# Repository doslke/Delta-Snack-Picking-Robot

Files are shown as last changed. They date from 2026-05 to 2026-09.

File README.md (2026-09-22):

# Delta Robot Snack Picking Prototype

An automated snack-picking and weighing system built around a three-axis Delta robot. A Python controller uses an overhead camera, a Qwen vision model, and an ArUco marker to locate products and guide the moving platform. ESP32 firmware drives the servos, vacuum pump relay, and HX711 load cell. A WeChat mini-program displays a cloud-backed cart and order flow.

The system was built and tested as a physical prototype.

## Contents

- [Features](#features)
- [Technology stack](#technology-stack)
- [Architecture](#architecture)
- [Repository structure](#repository-structure)
- [How the pipeline works](#how-the-pipeline-works)
- [Getting started](#getting-started)
- [Configuration and calibration](#configuration-and-calibration)
- [Firmware protocol](#firmware-protocol)
- [Cloud data flow](#cloud-data-flow)
- [Development notes](#development-notes)
- [License](#license)

## Features

| Area | Function |
| --- | --- |
| Product detection | Identify snack names and bounding boxes with qwen3-vl-plus |
| Visual servoing | Track ArUco marker ID 4 and adjust X/Y position with a PID controller |
| Pick and weigh | Control the pump, move items to the weighing station, and read the HX711 |
| Customer interface | Bind a cart by QR code, display weighed items, and create order records |
| Inventory management | Update product names over TCP port 8888 without restarting the controller |

## Technology stack

| Layer | Technology |
| --- | --- |
| Robot controller | Python 3.10+; OpenCV with ArUco support; NumPy; Pillow; DashScope SDK; python-dotenv |
| Vision | USB camera, OpenCV undistortion and ArUco detection, Alibaba Cloud qwen3-vl-plus for product detection |
| Control and communication | Two-axis PID in Python; newline-delimited TCP commands to the ESP32 on port 8266 |
| Firmware | ESP32 Arduino C++, FreeRTOS tasks, Wi-Fi, LEDC servo PWM, HX711 Arduino library, NVS Preferences |
| Customer application | WeChat Mini Program using TypeScript, WXML, and WXSS |
| Cloud backend | WeChat Cloud Development functions in JavaScript/Node.js with wx-server-sdk and a cloud database |
| Inventory desktop tool | Python, Tkinter, ttkbootstrap, pandas, and TCP sockets |
| Design artifacts | EasyEDA schematic/PCB JSON exports, SolidWorks part files, and XLSX bills of materials |

## Architecture

~~~text
Overhead USB camera
       |
       v
Python controller -- image --> qwen3-vl-plus
       |                         |
       |                   names + bounding boxes
       |                         |
       +<------------------------+
       |
       +-- ArUco tracking + PID --> TCP :8266 --> ESP32
       |                                      |--> 3 servo outputs
       |                                      |--> pump relay and button
       |                                      +--> HX711 load cell
       |
       +-- weighted item --> machineWeigh HTTP trigger
                                      |
                                      v
                              WeChat cloud database
                                      ^
                                      |
                        WeChat Mini Program polls cart
~~~

The camera provides image-space feedback. The firmware's **[OK]** response means a move was accepted and queued; **pos** reports the most recently commanded coordinates.

## Repository structure

~~~text
Delta-Snack-Picking-Robot/
├── README.md
├── LICENSE
├── BOM/                    Electrical and structural bills of materials
├── circuit/                EasyEDA schematic and PCB exports
├── models/                 SolidWorks part files
├── video.mp4               Demonstration media
└── src/
    ├── README.md           Detailed setup guide
    ├── .env.example         DashScope key template
    ├── controller/          Camera, vision, PID, TCP, pick, and cloud client
    ├── firmware/            ESP32 Arduino sketch
    ├── configer/            Desktop inventory-distribution tool
    └── wxapp/               Mini-program and cloud functions
~~~

The main implementation files are [main.py](src/controller/main.py), [vision.py](src/controller/vision.py), [servo.py](src/controller/servo.py), [robot.py](src/controller/robot.py), [cloud.py](src/controller/cloud.py), and [delta_robot.ino](src/firmware/delta_robot.ino). See the [setup guide](src/README.md) for module-level details.

## How the pipeline works

1. **Capture and detect.** The controller requests 1920 × 1080 camera frames. If dot25.npz is loaded, OpenCV corrects lens distortion. Press **s** to start the scan loop. A frame is sent to the configured vision model, which returns item names and normalized bounding boxes.
2. **Locate the end effector.** The controller detects an ArUco DICT_4X4_50 marker with ID 4 on the moving platform. A scan is skipped when the marker is not visible.
3. **Align.** For each detected item, the controller compares its box center with the marker center. The PID output is mapped to robot X/Y movement, clamped to a maximum step and workspace, and sent over TCP. The loop stops below a 15-pixel error by default or after 25 iterations.
4. **Pick.** The platform descends in 5 mm increments. The firmware toggles the pump and sends an event when its GPIO 27 button is pressed. The controller then lifts the platform and requests the weighing position.
5. **Weigh.** The firmware samples the HX711 before and after pump release, separated by a one-second delay, and returns the difference in grams.
6. **Report and rescan.** A positive weight is posted to the cloud function when its URL is configured. The controller scans again immediately after processing a detected batch; if no target is found, it retries after ten seconds.

One model scan supplies target positions for a batch. The next scan starts after the batch has been processed.

## Getting started

The following steps cover firmware, controller, and optional cloud configuration.

### 1. Prepare firmware and hardware

Use an ESP32-compatible Arduino environment with the HX711 library and open [delta_robot.ino](src/firmware/delta_robot.ino). Connect the three servos to GPIO **14, 12, 13**, the pump relay to **26**, the button to **27**, and HX711 DOUT/SCK to **33/32**.

The firmware stores Wi-Fi credentials in NVS. The command **setwifi SSID password** writes them; reboot to apply them. Serial and TCP both feed the command handler. Check the electrical design, motion limits, and pump polarity before powering the robot.

### 2. Prepare the Python controller

Install the Python dependencies:

~~~shell
python -m pip install opencv-contrib-python numpy pillow dashscope python-dotenv
~~~

From **src/**, copy **.env.example** to **.env** and set **DASHSCOPE_API_KEY**. The configuration module requires this variable even with **--no-robot**.

Set **ROBOT_IP** and calibration values in [config.py](src/controller/config.py). Update the camera intrinsics and inventory files for the installation.

### 3. Run

~~~shell
cd src
python -m controller.main
~~~

| Option | Purpose |
| --- | --- |
| **--camera N** | Select the camera index; default 0 |
| **--intrinsics PATH** | Select the calibration NPZ file |
| **--ip ADDRESS**, **--port N** | Override the robot TCP endpoint |
| **--no-robot** | Skip the robot connection and physical moves |
| **--save** | Save annotated detection images |

Press **s** to start the scan loop and **q** to quit. **--no-robot** skips robot communication and physical movement while retaining the vision and servo-loop code path.

### 4. Configure the optional WeChat demonstration

1. Replace **YOUR_ENV_ID** in [app.ts](src/wxapp/miniprogram/app.ts) with a cloud environment ID.
2. Deploy the four functions under [cloudfunctions](src/wxapp/cloudfunctions/) and create the **products**, **carts**, and **orders** collections. The optional **config** collection supplies the displayed logo.
3. Create product records whose **name** exactly matches expected vision names. Each product uses **unitPrice** as the price per 500 g and may include an **image**.
4. Enable the machineWeigh HTTP trigger and set **MACHINE_WEIGH_URL** in [config.py](src/controller/config.py). The default value is empty, so cloud posting is disabled until configured.
5. Set **CART_ID** to match the machine's QR code content. The mini-program validates its format and polls the cart record every three seconds.

## Configuration and calibration

| Setting | Default | Meaning |
| --- | ---: | --- |
| **ROBOT_PORT** | 8266 | ESP32 TCP command port |
| **INVENTORY_SERVER_PORT** | 8888 | TCP listener for inventory updates |
| **SERVO_KP / KI / KD** | 0.30 / 0 / 0.10 | Pixel-error PID gains |
| **SERVO_TOL_PX** | 15 | Alignment threshold |
| **SERVO_MAX_ITER** | 25 | Maximum alignment iterations |
| **SERVO_MAX_STEP_MM** | 50 | Maximum single PID move |
| **CAMERA_OFFSET_U / V** | −70 / −40 px | Camera alignment offsets |
| **DESCEND_STEP_MM** | 5 | Per-command descent increment |
| **WEIGH_X / Y / Z_MM** | 195 / 0 / 150 | Weighing position |

These values are in [config.py](src/controller/config.py). The firmware independently limits ordinary coordinates to X/Y **−100…100 mm** and Z **50…280 mm**, with the weighing position exempted. Keep host and firmware limits consistent. The HX711 factor defaults to **2280.0**; calibrate it with a known mass.

The optional [dot25.npz](src/controller/dot25.npz) stores **mtx** and **dist** camera-calibration arrays. If it cannot be read, undistortion is skipped. The controller requests a resolution; the actual image size depends on the camera and driver. Recalibrate the image-to-robot mapping and offsets after moving the camera.

## Firmware protocol

The firmware accepts UTF-8, newline-delimited text on TCP port 8266 and sends a **[HELLO]** line when connected. Its main commands are:

| Command | Response or effect |
| --- | --- |
| **x,y,z** | Request a Cartesian move; **[OK]** means queued, **[ERR]** means rejected |
| **pos** | Return last commanded coordinates and servo angles |
| **home** | Request the firmware home coordinates |
| **pump_on / pump_off / pump** | Set or query the pump relay |
| **weight** | Queue a differential load-cell reading; later return **[WEIGHT]** |
| **tare** | Zero the load cell |
| **ping** | Return **[PONG]** |
| **setwifi SSID password** | Save Wi-Fi credentials to NVS through the shared serial/TCP handler |

The firmware can also push a **[PUMP] ON (button)** message when the physical button toggles the relay. The controller uses this event during descent. A TCP client idle for roughly 30 seconds is disconnected; the Python controller sends periodic pings.

## Cloud data flow

~~~text
Python cloud.py -- one item --> machineWeigh
                                  |-- lookup products.name
                                  |-- compute weight × unitPrice / 500
                                  +-- write carts.snackList
                                             |
WeChat mini-program <-- getCartList ---------+
        |
        +-- simulated payment --> completeOrder --> orders + cart deletion
~~~

The relevant cloud functions are [machineWeigh](src/wxapp/cloudfunctions/machineWeigh/index.js), [getCartList](src/wxapp/cloudfunctions/getCartList/index.js), [validateCart](src/wxapp/cloudfunctions/validateCart/index.js), and [completeOrder](src/wxapp/cloudfunctions/completeOrder/index.js).

The Python client posts one weighed item per request. machineWeigh writes that request's snackList to the cart, so the current flow displays the latest reported item. validateCart checks the QR code's ID format and allows binding before the first item is reported. The mini-program simulates checkout and then calls completeOrder to create the order record.

## Development notes

- The inventory list guides the vision-model prompt. Add a name check after inference when strict catalog matching is required.
- machineWeigh replaces snackList on each report. Merge with the existing cart if the application needs multiple picks in one checkout.
- The payment handler uses a simulated success flow. Integrate a payment service before using it for transactions.
- Serial and TCP commands share the firmware handler, including **setwifi**. Restrict network access to the robot and add command authorization for networked deployments.
- Calibrate camera mapping, robot geometry, HX711 scaling, and motion timing for each installation.

## License

See [LICENSE](LICENSE) for the included GPL v3 license text.

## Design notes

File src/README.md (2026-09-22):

# Delta Robot Snack Picking Prototype: Source Guide

This directory contains the Python controller, ESP32 firmware, WeChat mini-program, and cloud functions for the physical prototype. See the [project overview](../README.md).

## Technology stack

| Component | Technology |
| --- | --- |
| Controller and vision | Python 3.10+, OpenCV/ArUco, NumPy, Pillow, DashScope SDK, python-dotenv |
| Robot firmware | ESP32 Arduino C++, FreeRTOS, Wi-Fi/TCP, LEDC PWM, HX711 library, NVS Preferences |
| Mini-program | TypeScript, WXML, WXSS, WeChat Mini Program APIs |
| Cloud functions | JavaScript/Node.js, wx-server-sdk, WeChat Cloud Development database |
| Inventory tool | Python, Tkinter, ttkbootstrap, pandas, TCP sockets |

## Source layout

| Path | Purpose |
| --- | --- |
| [controller/main.py](controller/main.py) | Program entry point, camera preview, scanning, and pick loop |
| [controller/vision.py](controller/vision.py) | qwen3-vl-plus calls, detection parsing, and ArUco recognition |
| [controller/servo.py](controller/servo.py) | Pixel-error PID control, stepwise descent, transfer, and weighing |
| [controller/robot.py](controller/robot.py) | TCP text-protocol client for the ESP32 |
| [controller/camera.py](controller/camera.py) | Camera capture and optional lens-distortion correction |
| [controller/cloud.py](controller/cloud.py) | Posts product names and weights to a cloud function |
| [controller/config.py](controller/config.py) | IP address, workspace, PID, positions, and other settings |
| [firmware/delta_robot.ino](firmware/delta_robot.ino) | ESP32 motion, pump, button, weighing, and network tasks |
| [wxapp](wxapp/) | Mini-program and the machineWeigh, getCartList, validateCart, and completeOrder cloud functions |
| [configer](configer/) | Desktop inventory tool that can push product names to the controller over TCP |

## Code path

1. The Python program reads camera frames and looks for ArUco marker ID 4 on the moving platform.
2. Pressing **s** calls the vision model for snack names and bounding boxes. If inventory.json is available, its names are added to the prompt.
3. The controller uses the pixel error between the marker and an item's center to calculate X/Y moves with a PID controller. It sends the moves over TCP until the error reaches a threshold or the iteration limit is exceeded.
4. The platform descends in steps. The GPIO 27 contact button toggles the pump and sends an event to Python.
5. At the weighing position, the firmware samples the HX711 twice. Python switches off the pump between the readings, and the firmware returns their difference.
6. If the weight is positive and a cloud-function URL is configured, Python posts the product name and weight. The mini-program polls the cart record every three seconds.

A firmware **[OK]** response means a move was accepted and queued, not that the platform arrived. The **pos** command reports the last commanded coordinates, not a separately measured physical position.

## Setup

Configure the firmware, controller, and cloud components in that order.

### ESP32

- Open [firmware/delta_robot.ino](firmware/delta_robot.ino) in an ESP32 Arduino environment with the HX711 library.
- Connect the three servos to GPIO 14/12/13, the pump relay to GPIO 26, the button to GPIO 27, and HX711 DOUT/SCK to GPIO 33/32.
- The firmware reads Wi-Fi credentials from NVS. The **setwifi SSID password** command saves them; reboot to apply them. Serial and TCP commands use the same handler.
- Calibrate the HX711 factor, robot geometry, weighing position, and motion limits for the installation.

### Python controller

- Use Python 3.10+ with OpenCV/ArUco, NumPy, Pillow, DashScope, and python-dotenv.
- Copy **.env.example** to **.env** and set **DASHSCOPE_API_KEY**. The configuration module reads this variable even with **--no-robot**.
- Set the robot IP, camera offsets, PID values, and positions in [controller/config.py](controller/config.py). The dot25.npz camera calibration must match the camera in use; the program skips undistortion if it cannot load the file.
- Edit [controller/inventory.json](controller/inventory.json), or push an inventory list from configer to the controller's TCP port 8888. A push updates the running list and writes the file.
- From this directory, run **python -m controller.main**. Available options include **--camera**, **--intrinsics**, **--ip**, **--port**, **--no-robot**, and **--save**. Press **s** to start automatic scanning and **q** to exit.

**--no-robot** skips the TCP connection and physical movements, but the program still attempts visual servoing after a detection.

### WeChat cloud demonstration

1. Replace **YOUR_ENV_ID** in [wxapp/miniprogram/app.ts](wxapp/miniprogram/app.ts) with the cloud environment ID.
2. Deploy the four cloud functions and create the products, carts, and orders collections. The optional config collection supplies the displayed brand image.
3. Product names in products must match the names returned by vision for pricing. machineWeigh calculates a subtotal from weight and price per 500 g.
4. Enable the machineWeigh HTTP trigger and set **MACHINE_WEIGH_URL** in [controller/config.py](controller/config.py). Its default is empty, so posting begins after configuration.
5. The mini-program scans a QR code containing a cart ID and polls the cloud record. validateCart mainly checks ID syntax; it can allow binding even before a matching carts record exists.

## Integration notes

- [machineWeigh](wxapp/cloudfunctions/machineWeigh/index.js) writes the latest reported item to snackList. Merge records there if a cart should hold multiple picks.
- The [mini-program payment handler](wxapp/miniprogram/pages/index/index.ts) simulates checkout and calls completeOrder. Connect a payment service for transactions.
- The inventory list guides the model prompt. Add a post-inference name check for strict catalog matching.
- Serial and TCP share the firmware command handler. Add authorization to the robot and the cloud weighing endpoint for networked deployments.

Recalibrate the camera, suction mechanism, load cell, and motion boundaries after mechanical changes.

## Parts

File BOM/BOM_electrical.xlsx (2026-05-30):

Name | Amount
DC Power Jack (DC-005, 5.5*2.5mm) | 1
2.54mm Single Row Straight Male/Female Pin Header | as suitable
16V 1000μF Radial Aluminum Electrolytic Capacitor | 3
ESP32 | 1
DCDC 12-5 MAX 8A | 2
L298N | 1
Pump 12V | 1

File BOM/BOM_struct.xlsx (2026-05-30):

Name | Amount
2020 Aluminum Profile 30cm | 3
2020 Aluminum Profile 20cm | 6
60-degree Extruded Corner Bracket (with 2020) | 6
90-degree Extruded Corner Bracket (with 2020) | 6
PU tube 6mm | 1
ZP2-TB20MBS-H5 SMC Bellows Vacuum Pad Unit | 1
Roller Lever Micro Switch | 1
MG 996r Servo | 3
M3 Brass Threaded Inserts | 3
M3 x 12 Fully Threaded Stud | 6
3mm Rod End Bearing | 6
M3 Nylon Insert Lock Nut | 18
M3 x 12 Socket Head Cap Screw | 6
T-Nuts Assortment Kit | 30
250mm M3 Threaded Rod | 3

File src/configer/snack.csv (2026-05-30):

sku | name | short_name | category | price | weight | length | width | height | z_pick | z_up | grab_type | place | keywords | remark
S001 | 三只松鼠碧根果 | 碧根果 | 坚果炒货 | 48.8 | 14 | 35 | 30 | 12 | 110 | 180 | suction | A1 | 坚果 | 备注
S002 | 百草味夏威夷果 | 夏威夷果 | 坚果炒货 | 55.8 | 12 | 34 | 29 | 11 | 110 | 180 | suction | A1 | 坚果 | 备注
S003 | 良品铺子巴旦木 | 巴旦木 | 坚果炒货 | 39.8 | 15 | 37 | 32 | 13 | 110 | 180 | suction | A1 | 坚果 | 备注
S004 | 恰恰腰果 | 腰果 | 坚果炒货 | 62.8 | 11 | 33 | 28 | 10 | 110 | 180 | suction | A1 | 坚果 | 备注
S005 | 三只松鼠开心果 | 开心果 | 坚果炒货 | 75.0 | 13 | 36 | 31 | 12 | 110 | 180 | suction | A1 | 坚果 | 备注
S006 | 百草味炭烧腰果 | 炭烧腰果 | 坚果炒货 | 59.9 | 11 | 33 | 28 | 10 | 110 | 180 | suction | A1 | 坚果 | 备注
S007 | 良品铺子琥珀核桃仁 | 琥珀核桃 | 坚果炒货 | 45.5 | 10 | 32 | 27 | 9 | 110 | 180 | suction | A1 | 坚果 | 备注
S008 | 恰恰纸皮核桃 | 纸皮核桃 | 坚果炒货 | 32.8 | 18 | 40 | 35 | 16 | 110 | 180 | suction | A1 | 坚果 | 备注
S009 | 三只松鼠松子 | 松子 | 坚果炒货 | 68.0 | 10 | 32 | 27 | 9 | 110 | 180 | suction | A1 | 坚果 | 备注
S010 | 百草味榛子 | 榛子 | 坚果炒货 | 52.5 | 12 | 34 | 29 | 11 | 110 | 180 | suction | A1 | 坚果 | 备注
S011 | 甘源蒜香青豆 | 蒜香青豆 | 炒货 | 12.8 | 8 | 25 | 20 | 6 | 80 | 150 | clamp | B1 | 炒货 | 备注
S012 | 恰恰原味青豆 | 原味青豆 | 炒货 | 11.5 | 8 | 25 | 20 | 6 | 80 | 150 | clamp | B1 | 炒货 | 备注
S013 | 华味亨香辣花生 | 香辣花生 | 炒货 | 15.9 | 10 | 28 | 23 | 7 | 80 | 150 | clamp | B1 | 炒货 | 备注
S014 | 老街口五香花生 | 五香花生 | 炒货 | 14.5 | 10 | 28 | 23 | 7 | 80 | 150 | clamp | B1 | 炒货 | 备注
S015 | 百草味蜂蜜花生 | 蜂蜜花生 | 炒货 | 16.2 | 10 | 28 | 23 | 7 | 80 | 150 | clamp | B1 | 炒货 | 备注
S016 | 甘源蟹黄瓜子仁 | 蟹黄瓜子仁 | 炒货 | 18.8 | 7 | 24 | 19 | 5 | 80 | 150 | clamp | B1 | 炒货 | 备注
S017 | 良品铺子牛肉味蚕豆 | 牛肉蚕豆 | 炒货 | 13.9 | 9 | 27 | 22 | 6 | 80 | 150 | clamp | B1 | 炒货 | 备注
S018 | 恰恰原味蚕豆 | 原味蚕豆 | 炒货 | 12.5 | 9 | 27 | 22 | 6 | 80 | 150 | clamp | B1 | 炒货 | 备注
S019 | 口水娃香辣蚕豆 | 香辣蚕豆 | 炒货 | 14.2 | 9 | 27 | 22 | 6 | 80 | 150 | clamp | B1 | 炒货 | 备注
S020 | 恰恰南瓜子 | 南瓜子 | 炒货 | 13.5 | 8 | 25 | 20 | 6 | 80 | 150 | clamp | B1 | 炒货 | 备注
S021 | 恰恰葵花籽 | 葵花籽 | 炒货 | 10.8 | 7 | 24 | 19 | 5 | 80 | 150 | clamp | B1 | 炒货 | 备注
S022 | 恰恰西瓜子 | 西瓜子 | 炒货 | 12.2 | 8 | 25 | 20 | 6 | 80 | 150 | clamp | B1 | 炒货 | 备注
S023 | 三只松鼠蒜香花生 | 蒜香花生 | 炒货 | 15.5 | 10 | 28 | 23 | 7 | 80 | 150 | clamp | B1 | 炒货 | 备注
S024 | 恰恰黑豆 | 黑豆 | 炒货 | 14.8 | 9 | 27 | 22 | 6 | 80 | 150 | clamp | B1 | 炒货 | 备注
S025 | 三只松鼠鹰嘴豆 | 鹰嘴豆 | 炒货 | 16.5 | 9 | 27 | 22 | 6 | 80 | 150 | clamp | B1 | 炒货 | 备注
S026 | 良品铺子芒果干 | 芒果干 | 果干 | 25.8 | 9 | 27 | 22 | 6 | 90 | 160 | clamp | C1 | 果干 | 备注
S027 | 百草味草莓干 | 草莓干 | 果干 | 23.5 | 8 | 26 | 21 | 5 | 90 | 160 | clamp | C1 | 果干 | 备注
S028 | 三只松鼠蔓越莓干 | 蔓越莓干 | 果干 | 22.6 | 7 | 25 | 20 | 5 | 90 | 160 | clamp | C1 | 果干 | 备注
S029 | 百草味蓝莓干 | 蓝莓干 | 果干 | 28.2 | 7 | 25 | 20 | 5 | 90 | 160 | clamp | C1 | 果干 | 备注
S030 | 良品铺子黄桃干 | 黄桃干 | 果干 | 21.9 | 8 | 26 | 21 | 5 | 90 | 160 | clamp | C1 | 果干 | 备注
S031 | 华味亨杏干 | 杏干 | 果干 | 20.8 | 8 | 26 | 21 | 5 | 90 | 160 | clamp | C1 | 果干 | 备注
S032 | 三只松鼠西梅干 | 西梅干 | 果干 | 29.9 | 9 | 27 | 22 | 6 | 90 | 160 | clamp | C1 | 果干 | 备注
S033 | 良品铺子话梅肉 | 话梅肉 | 果干 | 18.5 | 6 | 24 | 19 | 5 | 90 | 160 | clamp | C1 | 果干 | 备注
S034 | 华味亨情人梅 | 情人梅 | 果干 | 17.8 | 7 | 25 | 20 | 5 | 90 | 160 | clamp | C1 | 果干 | 备注
S035 | 华味亨老婆梅 | 老婆梅 | 果干 | 18.2 | 7 | 25 | 20 | 5 | 90 | 160 | clamp | C1 | 果干 | 备注
S036 | 良品铺子九制话梅 | 九制话梅 | 果干 | 19.5 | 7 | 25 | 20 | 5 | 90 | 160 | clamp | C1 | 果干 | 备注
S037 | 良品铺子菠萝干 | 菠萝干 | 果干 | 22.2 | 8 | 26 | 21 | 5 | 90 | 160 | clamp | C1 | 果干 | 备注
S038 | 华味亨柠檬片 | 柠檬片 | 果干 | 16.9 | 5 | 23 | 18 | 4 | 90 | 160 | clamp | C1 | 果干 | 备注
S039 | 良品铺子荔枝干 | 荔枝干 | 果干 | 21.8 | 8 | 26 | 21 | 5 | 90 | 160 | clamp | C1 | 果干 | 备注
S040 | 百草味桂圆干 | 桂圆干 | 果干 | 22.5 | 8 | 26 | 21 | 5 | 90 | 160 | clamp | C1 | 果干 | 备注
S041 | 华味亨乌梅 | 乌梅 | 果干 | 20.8 | 7 | 25 | 20 | 5 | 90 | 160 | clamp | C1 | 果干 | 备注
S042 | 百草味樱桃干 | 樱桃干 | 果干 | 25.5 | 8 | 26 | 21 | 5 | 90 | 160 | clamp | C1 | 果干 | 备注
S043 | 良品铺子原味猪肉脯 | 原味肉脯 | 肉干 | 32.2 | 10 | 28 | 23 | 7 | 100 | 170 | clamp | D1 | 肉干 | 备注
S044 | 三只松鼠香辣肉脯 | 香辣肉脯 | 肉干 | 33.5 | 10 | 28 | 23 | 7 | 100 | 170 | clamp | D1 | 肉干 | 备注
S045 | 百草味蜜汁肉脯 | 蜜汁肉脯 | 肉干 | 32.8 | 10 | 28 | 23 | 7 | 100 | 170 | clamp | D1 | 肉干 | 备注
S046 | 百草味黑椒肉脯 | 黑椒肉脯 | 肉干 | 34.2 | 10 | 28 | 23 | 7 | 100 | 170 | clamp | D1 | 肉干 | 备注
S047 | 华味亨五香猪肉干 | 五香肉干 | 肉干 | 31.6 | 11 | 29 | 24 | 8 | 100 | 170 | clamp | D1 | 肉干 | 备注
S048 | 百草味沙爹肉干 | 沙爹肉干 | 肉干 | 32.2 | 11 | 29 | 24 | 8 | 100 | 170 | clamp | D1 | 肉干 | 备注
S049 | 三只松鼠麻辣牛肉干 | 麻辣牛肉 | 肉干 | 39.8 | 10 | 28 | 23 | 7 | 100 | 170 | clamp | D1 | 肉干 | 备注
S050 | 良品铺子五香牛肉干 | 五香牛肉 | 肉干 | 38.5 | 10 | 28 | 23 | 7 | 100 | 170 | clamp | D1 | 肉干 | 备注
S051 | 川奈良品风干牛肉 | 风干牛肉 | 肉干 | 45.9 | 11 | 29 | 24 | 8 | 100 | 170 | clamp | D1 | 肉干 | 备注
S052 | 良品铺子牛肉粒 | 牛肉粒 | 肉干 | 38.9 | 8 | 26 | 21 | 5 | 100 | 170 | clamp | D1 | 肉干 | 备注
S053 | 三只松鼠风干猪肉 | 风干猪肉 | 肉干 | 34.8 | 10 | 28 | 23 | 7 | 100 | 170 | clamp | D1 | 肉干 | 备注
S054 | 百草味香辣鱿鱼丝 | 鱿鱼丝 | 海味 | 26.6 | 8 | 26 | 21 | 5 | 95 | 165 | clamp | E1 | 海味 | 备注
S055 | 良品铺子原味鱿鱼丝 | 原味鱿鱼丝 | 海味 | 25.8 | 8 | 26 | 21 | 5 | 95 | 165 | clamp | E1 | 海味 | 备注
S056 | 三只松鼠带籽鱿鱼仔 | 鱿鱼仔 | 海味 | 29.5 | 9 | 27 | 22 | 6 | 95 | 165 | clamp | E1 | 海味 | 备注
S057 | 劲仔香酥带鱼 | 香酥带鱼 | 海味 | 24.9 | 9 | 27 | 22 | 6 | 95 | 165 | clamp | E1 | 海味 | 备注
S058 | 良品铺子香辣小黄鱼 | 小黄鱼 | 海味 | 25.5 | 8 | 26 | 21 | 5 | 95 | 165 | clamp | E1 | 海味 | 备注
S059 | 三只松鼠鳕鱼片 | 鳕鱼片 | 海味 | 25.5 | 8 | 26 | 21 | 5 | 95 | 165 | clamp | E1 | 海味 | 备注
S060 | 百草味鱿鱼头 | 鱿鱼头 | 海味 | 26.2 | 9 | 27 | 22 | 6 | 95 | 165 | clamp | E1 | 海味 | 备注
S061 | 良品铺子鱼柳 | 鱼柳 | 海味 | 25.2 | 8 | 26 | 21 | 5 | 95 | 165 | clamp | E1 | 海味 | 备注
S062 | 三只松鼠鱿鱼足 | 鱿鱼足 | 海味 | 27.5 | 10 | 28 | 23 | 7 | 95 | 165 | clamp | E1 | 海味 | 备注
S063 | 盐津铺子香辣海带结 | 海带结 | 海味 | 15.9 | 7 | 25 | 20 | 5 | 95 | 165 | clamp | E1 | 海味 | 备注
S064 | 卫龙香辣海带丝 | 海带丝 | 海味 | 14.9 | 6 | 24 | 19 | 4 | 95 | 165 | clamp | E1 | 海味 | 备注
S065 | 盐津铺子香辣鱼豆腐 | 鱼豆腐 | 豆制品 | 18.8 | 8 | 26 | 21 | 5 | 85 | 155 | clamp | F1 | 豆制品 | 备注
S066 | 良品铺子原味鱼豆腐 | 原味鱼豆腐 | 豆制品 | 18.2 | 8 | 26 | 21 | 5 | 85 | 155 | clamp | F1 | 豆制品 | 备注
S067 | 卫龙香辣魔芋爽 | 魔芋爽 | 豆制品 | 14.9 | 6 | 24 | 19 | 4 | 85 | 155 | clamp | F1 | 豆制品 | 备注
S068 | 三只松鼠麻酱魔芋爽 | 麻酱魔芋 | 豆制品 | 15.5 | 6 | 24 | 19 | 4 | 85 | 155 | clamp | F1 | 豆制品 | 备注
S069 | 邬辣妈麻辣素牛肉 | 素牛肉 | 豆制品 | 16.2 | 7 | 25 | 20 | 5 | 85 | 155 | clamp | F1 | 豆制品 | 备注
S070 | 盐津铺子麻辣豆干 | 麻辣豆干 | 豆制品 | 15.6 | 7 | 25 | 20 | 5 | 85 | 155 | clamp | F1 | 豆制品 | 备注
S071 | 良品铺子五香豆干 | 五香豆干 | 豆制品 | 15.2 | 7 | 25 | 20 | 5 | 85 | 155 | clamp | F1 | 豆制品 | 备注
S072 | 百草味香菇豆干 | 香菇豆干 | 豆制品 | 16.5 | 7 | 25 | 20 | 5 | 85 | 155 | clamp | F1 | 豆制品 | 备注
S073 | 盐津铺子泡椒豆干 | 泡椒豆干 | 豆制品 | 15.8 | 7 | 25 | 20 | 5 | 85 | 155 | clamp | F1 | 豆制品 | 备注
S074 | 三只松鼠香辣手撕素肉 | 手撕素肉 | 豆制品 | 17.8 | 8 | 26 | 21 | 5 | 85 | 155 | clamp | F1 | 豆制品 | 备注
S075 | 邬辣妈素排 | 素排 | 豆制品 | 17.2 | 7 | 25 | 20 | 5 | 85 | 155 | clamp | F1 | 豆制品 | 备注
S076 | 盐津铺子素鸡 | 素鸡 | 豆制品 | 16.5 | 7 | 25 | 20 | 5 | 85 | 155 | clamp | F1 | 豆制品 | 备注
S077 | 邬辣妈豆卷 | 豆卷 | 豆制品 | 16.2 | 7 | 25 | 20 | 5 | 85 | 155 | clamp | F1 | 豆制品 | 备注
S078 | 卫龙大面筋辣条 | 大面筋 | 豆制品 | 13.9 | 7 | 25 | 20 | 5 | 85 | 155 | clamp | F1 | 豆制品 | 备注
S079 | 三只松鼠小辣棒辣条 | 小辣棒 | 豆制品 | 14.2 | 6 | 24 | 19 | 4 | 85 | 155 | clamp | F1 | 豆制品 | 备注
S080 | 良品铺子大刀肉辣条 | 大刀肉 | 豆制品 | 14.5 | 7 | 25 | 20 | 5 | 85 | 155 | clamp | F1 | 豆制品 | 备注
S081 | 乐事原味薯片 | 原味薯片 | 膨化 | 15.5 | 7 | 25 | 20 | 5 | 80 | 150 | clamp | G1 | 膨化 | 备注
S082 | 乐事番茄薯片 | 番茄薯片 | 膨化 | 15.8 | 7 | 25 | 20 | 5 | 80 | 150 | clamp | G1 | 膨化 | 备注
S083 | 可比克烧烤薯片 | 烧烤薯片 | 膨化 | 15.9 | 7 | 25 | 20 | 5 | 80 | 150 | clamp | G1 | 膨化 | 备注
S084 | 好丽友黄瓜薯片 | 黄瓜薯片 | 膨化 | 15.6 | 7 | 25 | 20 | 5 | 80 | 150 | clamp | G1 | 膨化 | 备注
S085 | 三只松鼠番茄山药脆片 | 番茄山药 | 膨化 | 17.8 | 7 | 25 | 20 | 5 | 80 | 150 | clamp | G1 | 膨化 | 备注
S086 | 良品铺子麻辣山药脆片 | 麻辣山药 | 膨化 | 18.2 | 7 | 25 | 20 | 5 | 80 | 150 | clamp | G1 | 膨化 | 备注
S087 | 爱尚咪咪虾条 | 咪咪虾条 | 膨化 | 14.5 | 6 | 24 | 19 | 4 | 80 | 150 | clamp | G1 | 膨化 | 备注
S088 | 爱尚蟹味粒 | 蟹味粒 | 膨化 | 14.8 | 6 | 24 | 19 | 4 | 80 | 150 | clamp | G1 | 膨化 | 备注
S089 | 旺旺原味小小酥 | 原味小小酥 | 膨化 | 15.9 | 7 | 25 | 20 | 5 | 80 | 150 | clamp | G1 | 膨化 | 备注
S090 | 三只松鼠黑胡椒小小酥 | 黑椒小小酥 | 膨化 | 16.2 | 7 | 25 | 20 | 5 | 80 | 150 | clamp | G1 | 膨化 | 备注
S091 | 恰恰原味锅巴 | 原味锅巴 | 膨化 | 16.5 | 8 | 26 | 21 | 5 | 80 | 150 | clamp | G1 | 膨化 | 备注
S092 | 良品铺子香辣锅巴 | 香辣锅巴 | 膨化 | 16.8 | 8 | 26 | 21 | 5 | 80 | 150 | clamp | G1 | 膨化 | 备注
S093 | 百草味蟹黄锅巴 | 蟹黄锅巴 | 膨化 | 17.5 | 8 | 26 | 21 | 5 | 80 | 150 | clamp | G1 | 膨化 | 备注
S094 | 良品铺子川辣锅巴 | 川辣锅巴 | 膨化 | 16.9 | 8 | 26 | 21 | 5 | 80 | 150 | clamp | G1 | 膨化 | 备注
S095 | 恰恰小米锅巴 | 小米锅巴 | 膨化 | 16.5 | 8 | 26 | 21 | 5 | 80 | 150 | clamp | G1 | 膨化 | 备注
S096 | 三只松鼠麻辣土豆丝 | 麻辣土豆丝 | 膨化 | 14.9 | 7 | 25 | 20 | 5 | 80 | 150 | clamp | G1 | 膨化 | 备注
S097 | 良品铺子香辣土豆片 | 香辣土豆片 | 膨化 | 15.2 | 7 | 25 | 20 | 5 | 80 | 150 | clamp | G1 | 膨化 | 备注
S098 | 乐事原味薯条 | 原味薯条 | 膨化 | 15.8 | 7 | 25 | 20 | 5 | 80 | 150 | clamp | G1 | 膨化 | 备注
S099 | 三只松鼠蔬菜卷 | 蔬菜卷 | 膨化 | 15.5 | 7 | 25 | 20 | 5 | 80 | 150 | clamp | G1 | 膨化 | 备注
S100 | 三惠尖角脆 | 尖角脆 | 膨化 | 16.2 | 7 | 25 | 20 | 5 | 80 | 150 | clamp | G1 | 膨化 | 备注
S101 | 旺旺玉米花 | 玉米花 | 膨化 | 14.2 | 6 | 24 | 19 | 4 | 80 | 150 | clamp | G1 | 膨化 | 备注
S102 | 三只松鼠奶油玉米泡 | 奶油玉米泡 | 膨化 | 15.2 | 7 | 25 | 20 | 5 | 80 | 150 | clamp | G1 | 膨化 | 备注
S103 | 百草味巧克力玉米泡 | 巧克力玉米泡 | 膨化 | 15.5 | 7 | 25 | 20 | 5 | 80 | 150 | clamp | G1 | 膨化 | 备注
S104 | 麦酥园香葱薄脆饼干 | 香葱薄脆 | 饼干 | 14.5 | 7 | 25 | 20 | 5 | 75 | 145 | clamp | H1 | 饼干 | 备注
S105 | 百草味香葱薄脆饼干 | 百草香葱薄脆 | 饼干 | 14.9 | 7 | 25 | 20 | 5 | 75 | 145 | clamp | H1 | 饼干 | 备注
S106 | 比比赞日式海盐小圆饼 | 海盐小圆饼 | 饼干 | 16.2 | 6 | 24 | 19 | 4 | 75 | 145 | clamp | H1 | 饼干 | 备注
S107 | 麦酥园蔬菜薄脆饼干 | 蔬菜薄脆 | 饼干 | 13.5 | 6 | 24 | 19 | 4 | 75 | 145 | clamp | H1 | 饼干 | 备注
S108 | 好丽友咸蛋黄麦芽饼 | 麦芽饼 | 饼干 | 17.6 | 7 | 25 | 20 | 5 | 75 | 145 | clamp | H1 | 饼干 | 备注
S109 | 达利园鸡蛋煎饼 | 鸡蛋煎饼 | 饼干 | 15.5 | 7 | 25 | 20 | 5 | 75 | 145 | clamp | H1 | 饼干 | 备注
S110 | 旺旺牛奶饼干 | 牛奶饼干 | 饼干 | 14.2 | 7 | 25 | 20 | 5 | 75 | 145 | clamp | H1 | 饼干 | 备注
S111 | 奥利奥巧克力饼干 | 巧克力饼干 | 饼干 | 16.8 | 7 | 25 | 20 | 5 | 75 | 145 | clamp | H1 | 饼干 | 备注
S112 | 良品铺子香葱苏打饼干 | 香葱苏打 | 饼干 | 14.9 | 7 | 25 | 20 | 5 | 75 | 145 | clamp | H1 | 饼干 | 备注
S113 | 百草味奶盐苏打饼干 | 奶盐苏打 | 饼干 | 14.5 | 7 | 25 | 20 | 5 | 75 | 145 | clamp | H1 | 饼干 | 备注
S114 | 良品铺子全麦苏打饼干 | 全麦苏打 | 饼干 | 15.2 | 7 | 25 | 20 | 5 | 75 | 145 | clamp | H1 | 饼干 | 备注
S115 | 格力高黄油曲奇饼干 | 黄油曲奇 | 饼干 | 17.5 | 7 | 25 | 20 | 5 | 75 | 145 | clamp | H1 | 饼干 | 备注
S116 | 趣多多巧克力曲奇饼干 | 巧克力曲奇 | 饼干 | 18.2 | 7 | 25 | 20 | 5 | 75 | 145 | clamp | H1 | 饼干 | 备注
S117 | 百草味抹茶曲奇饼干 | 抹茶曲奇 | 饼干 | 18.5 | 7 | 25 | 20 | 5 | 75 | 145 | clamp | H1 | 饼干 | 备注
S118 | 好丽友草莓夹心饼干 | 草莓夹心 | 饼干 | 16.8 | 7 | 25 | 20 | 5 | 75 | 145 | clamp | H1 | 饼干 | 备注
S119 | 达利园巧克力夹心饼干 | 巧克力夹心 | 饼干 | 17.2 | 7 | 25 | 20 | 5 | 75 | 145 | clamp | H1 | 饼干 | 备注
S120 | 格力高巧克力威化饼干 | 巧克力威化 | 饼干 | 16.2 | 7 | 25 | 20 | 5 | 75 | 145 | clamp | H1 | 饼干 | 备注
S121 | 百草味牛奶威化饼干 | 牛奶威化 | 饼干 | 15.8 | 7 | 25 | 20 | 5 | 75 | 145 | clamp | H1 | 饼干 | 备注
S122 | 达利园早餐饼干 | 早餐饼干 | 饼干 | 15.5 | 7 | 25 | 20 | 5 | 75 | 145 | clamp | H1 | 饼干 | 备注
S123 | 比比赞芝士味饼干 | 芝士饼干 | 饼干 | 15.8 | 7 | 25 | 20 | 5 | 75 | 145 | clamp | H1 | 饼干 | 备注
S124 | 麦酥园牛乳味饼干 | 牛乳饼干 | 饼干 | 15.2 | 7 | 25 | 20 | 5 | 75 | 145 | clamp | H1 | 饼干 | 备注
S125 | 老街口红糖小麻花 | 红糖麻花 | 糕点 | 18.2 | 8 | 26 | 21 | 5 | 90 | 160 | clamp | I1 | 糕点 | 备注
S126 | 口水娃椒盐小麻花 | 椒盐麻花 | 糕点 | 17.8 | 8 | 26 | 21 | 5 | 90 | 160 | clamp | I1 | 糕点 | 备注
S127 | 友臣蜂蜜小麻花 | 蜂蜜麻花 | 糕点 | 18.5 | 8 | 26 | 21 | 5 | 90 | 160 | clamp | I1 | 糕点 | 备注
S128 | 三只松鼠香辣小麻花 | 香辣麻花 | 糕点 | 17.2 | 8 | 26 | 21 | 5 | 90 | 160 | clamp | I1 | 糕点 | 备注
S129 | 百草味抹茶麻薯 | 抹茶麻薯 | 糕点 | 19.5 | 8 | 26 | 21 | 5 | 90 | 160 | clamp | I1 | 糕点 | 备注
S130 | 良品铺子红豆麻薯 | 红豆麻薯 | 糕点 | 19.2 | 8 | 26 | 21 | 5 | 90 | 160 | clamp | I1 | 糕点 | 备注
S131 | 三只松鼠芒果麻薯 | 芒果麻薯 | 糕点 | 19.8 | 8 | 26 | 21 | 5 | 90 | 160 | clamp | I1 | 糕点 | 备注
S132 | 旺旺香草糯米糍 | 香草糯米糍 | 糕点 | 18.9 | 7 | 25 | 20 | 5 | 90 | 160 | clamp | I1 | 糕点 | 备注
S133 | 百草味巧克力糯米糍 | 巧克力糯米糍 | 糕点 | 19.2 | 7 | 25 | 20 | 5 | 90 | 160 | clamp | I1 | 糕点 | 备注
S134 | 杏花楼桂花糕 | 桂花糕 | 糕点 | 17.8 | 7 | 25 | 20 | 5 | 90 | 160 | clamp | I1 | 糕点 | 备注
S135 | 良品铺子绿豆糕 | 绿豆糕 | 糕点 | 16.5 | 7 | 25 | 20 | 5 | 90 | 160 | clamp | I1 | 糕点 | 备注
S136 | 百草味红豆糕 | 红豆糕 | 糕点 | 16.8 | 7 | 25 | 20 | 5 | 90 | 160 | clamp | I1 | 糕点 | 备注
S137 | 徐福记凤梨酥 | 凤梨酥 | 糕点 | 19.6 | 8 | 26 | 21 | 5 | 90 | 160 | clamp | I1 | 糕点 | 备注
S138 | 达利园老婆饼 | 老婆饼 | 糕点 | 17.2 | 7 | 25 | 20 | 5 | 90 | 160 | clamp | I1 | 糕点 | 备注
S139 | 徐福记糯米老婆饼 | 糯米老婆饼 | 糕点 | 17.8 | 7 | 25 | 20 | 5 | 90 | 160 | clamp | I1 | 糕点 | 备注
S140 | 三只松鼠原味雪花酥 | 原味雪花酥 | 糕点 | 20.8 | 8 | 26 | 21 | 5 | 90 | 160 | clamp | I1 | 糕点 | 备注
S141 | 百草味抹茶雪花酥 | 抹茶雪花酥 | 糕点 | 21.2 | 8 | 26 | 21 | 5 | 90 | 160 | clamp | I1 | 糕点 | 备注
S142 | 良品铺子巧克力雪花酥 | 巧克力雪花酥 | 糕点 | 21.5 | 8 | 26 | 21 | 5 | 90 | 160 | clamp | I1 | 糕点 | 备注
S143 | 良品铺子原味蒸蛋糕 | 原味蒸蛋糕 | 糕点 | 18.2 | 8 | 26 | 21 | 5 | 90 | 160 | clamp | I1 | 糕点 | 备注
S144 | 百草味芝士蒸蛋糕 | 芝士蒸蛋糕 | 糕点 | 18.8 | 8 | 26 | 21 | 5 | 90 | 160 | clamp | I1 | 糕点 | 备注
S145 | 达利园纸杯小蛋糕 | 纸杯蛋糕 | 糕点 | 19.5 | 7 | 25 | 20 | 5 | 90 | 160 | clamp | I1 | 糕点 | 备注
S146 | 三只松鼠玛芬小蛋糕 | 玛芬蛋糕 | 糕点 | 20.2 | 7 | 25 | 20 | 5 | 90 | 160 | clamp | I1 | 糕点 | 备注
S147 | 百草味红豆铜锣烧 | 红豆铜锣烧 | 糕点 | 18.9 | 8 | 26 | 21 | 5 | 90 | 160 | clamp | I1 | 糕点 | 备注
S148 | 良品铺子抹茶铜锣烧 | 抹茶铜锣烧 | 糕点 | 19.5 | 8 | 26 | 21 | 5 | 90 | 160 | clamp | I1 | 糕点 | 备注
S149 | 三只松鼠原味蛋黄酥 | 原味蛋黄酥 | 糕点 | 22.8 | 9 | 27 | 22 | 6 | 90 | 160 | clamp | I1 | 糕点 | 备注
S150 | 百草味芋泥蛋黄酥 | 芋泥蛋黄酥 | 糕点 | 23.5 | 9 | 27 | 22 | 6 | 90 | 160 | clamp | I1 | 糕点 | 备注
S151 | 良品铺子海苔肉松小贝 | 海苔肉松小贝 | 糕点 | 24.2 | 8 | 26 | 21 | 5 | 90 | 160 | clamp | I1 | 糕点 | 备注
S152 | 三只松鼠草莓肉松小贝 | 草莓肉松小贝 | 糕点 | 24.8 | 8 | 26 | 21 | 5 | 90 | 160 | clamp | I1 | 糕点 | 备注
S153 | 达利园桃酥 | 桃酥 | 糕点 | 16.8 | 7 | 25 | 20 | 5 | 90 | 160 | clamp | I1 | 糕点 | 备注
S154 | 徐福记酥饼 | 酥饼 | 糕点 | 17.2 | 7 | 25 | 20 | 5 | 90 | 160 | clamp | I1 | 糕点 | 备注
S155 | 杏花楼龙须酥 | 龙须酥 | 糕点 | 18.9 | 7 | 25 | 20 | 5 | 90 | 160 | clamp | I1 | 糕点 | 备注
S156 | 徐福记芝麻糕 | 芝麻糕 | 糕点 | 17.5 | 7 | 25 | 20 | 5 | 90 | 160 | clamp | I1 | 糕点 | 备注
S157 | 杏花楼芝麻球 | 芝麻球 | 糕点 | 18.5 | 7 | 25 | 20 | 5 | 90 | 160 | clamp | I1 | 糕点 | 备注
S158 | 杏花楼冰皮月饼 | 冰皮月饼 | 糕点 | 22.5 | 9 | 27 | 22 | 6 | 90 | 160 | clamp | I1 | 糕点 | 备注
S159 | 五芳斋五仁月饼 | 五仁月饼 | 糕点 | 21.2 | 10 | 28 | 23 | 7 | 90 | 160 | clamp | I1 | 糕点 | 备注
S160 | 徐福记原味牛轧糖 | 原味牛轧糖 | 糖果 | 17.2 | 7 | 25 | 20 | 5 | 85 | 155 | clamp | J1 | 糖果 | 备注
S161 | 三只松鼠抹茶牛轧糖 | 抹茶牛轧糖 | 糖果 | 17.8 | 7 | 25 | 20 | 5 | 85 | 155 | clamp | J1 | 糖果 | 备注
S162 | 百草味巧克力牛轧糖 | 巧克力牛轧糖 | 糖果 | 18.2 | 7 | 25 | 20 | 5 | 85 | 155 | clamp | J1 | 糖果 | 备注
S163 | 三只松鼠蔓越莓牛轧糖 | 蔓越莓牛轧糖 | 糖果 | 18.5 | 7 | 25 | 20 | 5 | 85 | 155 | clamp | J1 | 糖果 | 备注
S164 | 徐福记花生酥 | 花生酥 | 糖果 | 16.5 | 7 | 25 | 20 | 5 | 85 | 155 | clamp | J1 | 糖果 | 备注
S165 | 徐福记芝麻酥 | 芝麻酥 | 糖果 | 16.8 | 7 | 25 | 20 | 5 | 85 | 155 | clamp | J1 | 糖果 | 备注
S166 | 徐福记核桃酥 | 核桃酥 | 糖果 | 17.2 | 7 | 25 | 20 | 5 | 85 | 155 | clamp | J1 | 糖果 | 备注
S167 | 徐福记大虾酥 | 大虾酥 | 糖果 | 15.5 | 7 | 25 | 20 | 5 | 85 | 155 | clamp | J1 | 糖果 | 备注
S168 | 徐福记高粱饴 | 高粱饴 | 糖果 | 14.2 | 7 | 25 | 20 | 5 | 85 | 155 | clamp | J1 | 糖果 | 备注
S169 | 马大姐牛皮糖 | 牛皮糖 | 糖果 | 15.5 | 7 | 25 | 20 | 5 | 85 | 155 | clamp | J1 | 糖果 | 备注
S170 | 徐福记奶片 | 奶片 | 糖果 | 15.8 | 6 | 24 | 19 | 4 | 85 | 155 | clamp | J1 | 糖果 | 备注
S171 | 大白兔原味奶糖 | 原味奶糖 | 糖果 | 14.8 | 6 | 24 | 19 | 4 | 85 | 155 | clamp | J1 | 糖果 | 备注
S172 | 阿尔卑斯巧克力奶糖 | 巧克力奶糖 | 糖果 | 15.2 | 6 | 24 | 19 | 4 | 85 | 155 | clamp | J1 | 糖果 | 备注
S173 | 阿尔卑斯牛奶棒棒糖 | 牛奶棒棒糖 | 糖果 | 14.2 | 5 | 23 | 18 | 4 | 85 | 155 | clamp | J1 | 糖果 | 备注
S174 | 徐福记水果棒棒糖 | 水果棒棒糖 | 糖果 | 13.9 | 5 | 23 | 18 | 4 | 85 | 155 | clamp | J1 | 糖果 | 备注
S175 | 雅客混合水果硬糖 | 混合水果糖 | 糖果 | 12.8 | 5 | 23 | 18 | 4 | 85 | 155 | clamp | J1 | 糖果 | 备注
S176 | 雅客柠檬水果硬糖 | 柠檬水果糖 | 糖果 | 13.2 | 5 | 23 | 18 | 4 | 85 | 155 | clamp | J1 | 糖果 | 备注
S177 | 喜之郎QQ糖 | QQ糖 | 糖果 | 13.5 | 6 | 24 | 19 | 4 | 85 | 155 | clamp | J1 | 糖果 | 备注
S178 | 喜之郎芒果软糖 | 芒果软糖 | 糖果 | 14.5 | 6 | 24 | 19 | 4 | 85 | 155 | clamp | J1 | 糖果 | 备注
S179 | 喜之郎荔枝软糖 | 荔枝软糖 | 糖果 | 14.2 | 6 | 24 | 19 | 4 | 85 | 155 | clamp | J1 | 糖果 | 备注
S180 | 悠哈混合橡皮糖 | 混合橡皮糖 | 糖果 | 14.2 | 6 | 24 | 19 | 4 | 85 | 155 | clamp | J1 | 糖果 | 备注
S181 | 绿箭无糖薄荷糖 | 无糖薄荷糖 | 糖果 | 11.5 | 5 | 23 | 18 | 4 | 85 | 155 | clamp | J1 | 糖果 | 备注
S182 | 金嗓子金银花润喉糖 | 金银花润喉糖 | 糖果 | 12.2 | 5 | 23 | 18 | 4 | 85 | 155 | clamp | J1 | 糖果 | 备注
S183 | 德芙黑巧夹心巧克力 | 黑巧夹心 | 巧克力 | 20.5 | 7 | 25 | 20 | 5 | 85 | 155 | clamp | J1 | 巧克力 | 备注
S184 | 费列罗牛奶夹心巧克力 | 牛奶夹心 | 巧克力 | 19.8 | 7 | 25 | 20 | 5 | 85 | 155 | clamp | J1 | 巧克力 | 备注
S185 | 明治松露巧克力 | 松露巧克力 | 巧克力 | 23.5 | 7 | 25 | 20 | 5 | 85 | 155 | clamp | J1 | 巧克力 | 备注
S186 | 格力高巧克力棒 | 巧克力棒 | 巧克力 | 18.2 | 6 | 24 | 19 | 4 | 85 | 155 | clamp | J1 | 巧克力 | 备注
S187 | 趣多多巧克力豆 | 巧克力豆 | 巧克力 | 17.5 | 6 | 24 | 19 | 4 | 85 | 155 | clamp | J1 | 巧克力 | 备注
S188 | 德芙巧克力块 | 巧克力块 | 巧克力 | 21.2 | 7 | 25 | 20 | 5 | 85 | 155 | clamp | J1 | 巧克力 | 备注
S189 | 德芙巧克力酱 | 巧克力酱 | 巧克力 | 20.5 | 7 | 25 | 20 | 5 | 85 | 155 | clamp | J1 | 巧克力 | 备注
S190 | 明治70%黑巧克力 | 70%黑巧克力 | 巧克力 | 23.8 | 7 | 25 | 20 | 5 | 85 | 155 | clamp | J1 | 巧克力 | 备注
S191 | 三只松鼠坚果能量棒 | 坚果能量棒 | 代餐 | 24.8 | 9 | 27 | 22 | 6 | 105 | 175 | clamp | K1 | 代餐 | 备注
S192 | 百草味谷物能量棒 | 谷物能量棒 | 代餐 | 23.5 | 9 | 27 | 22 | 6 | 105 | 175 | clamp | K1 | 代餐 | 备注
S193 | 良品铺子乳清蛋白棒 | 乳清蛋白棒 | 代餐 | 26.9 | 8 | 26 | 21 | 5 | 105 | 175 | clamp | K1 | 代餐 | 备注
S194 | 达利园原味燕麦棒 | 原味燕麦棒 | 代餐 | 20.6 | 8 | 26 | 21 | 5 | 105 | 175 | clamp | K1 | 代餐 | 备注
S195 | 三只松鼠水果燕麦棒 | 水果燕麦棒 | 代餐 | 21.2 | 8 | 26 | 21 | 5 | 105 | 175 | clamp | K1 | 代餐 | 备注
S196 | 冠生园原味压缩饼干 | 原味压缩饼干 | 代餐 | 16.8 | 10 | 28 | 23 | 7 | 105 | 175 | clamp | K1 | 代餐 | 备注
S197 | 达利园巧克力压缩饼干 | 巧克力压缩饼干 | 代餐 | 17.5 | 10 | 28 | 23 | 7 | 105 | 175 | clamp | K1 | 代餐 | 备注
S198 | 良品铺子原味全麦面包 | 原味全麦面包 | 代餐 | 18.2 | 12 | 30 | 25 | 8 | 105 | 175 | clamp | K1 | 代餐 | 备注
S199 | 百草味杂粮全麦面包 | 杂粮全麦面包 | 代餐 | 18.8 | 12 | 30 | 25 | 8 | 105 | 175 | clamp | K1 | 代餐 | 备注
S200 | 达利园奶香吐司面包 | 奶香吐司 | 代餐 | 17.9 | 11 | 29 | 24 | 7 | 105 | 175 | clamp | K1 | 代餐 | 备注
S201 | 三只松鼠抹茶吐司面包 | 抹茶吐司 | 代餐 | 18.5 | 11 | 29 | 24 | 7 | 105 | 175 | clamp | K1 | 代餐 | 备注
S202 | 良品铺子全麦吐司 | 全麦吐司 | 代餐 | 18.5 | 11 | 29 | 24 | 7 | 105 | 175 | clamp | K1 | 代餐 | 备注
S203 | 百草味杂粮吐司 | 杂粮吐司 | 代餐 | 19.2 | 11 | 29 | 24 | 7 | 105 | 175 | clamp | K1 | 代餐 | 备注
S204 | 良品铺子全麦饼干 | 全麦饼干 | 代餐 | 17.5 | 8 | 26 | 21 | 5 | 105 | 175 | clamp | K1 | 代餐 | 备注
S205 | 百草味杂粮饼 | 杂粮饼 | 代餐 | 18.2 | 8 | 26 | 21 | 5 | 105 | 175 | clamp | K1 | 代餐 | 备注
S206 | 桂格燕麦片 | 燕麦片 | 代餐 | 19.8 | 10 | 28 | 23 | 7 | 105 | 175 | clamp | K1 | 代餐 | 备注
S207 | 雀巢玉米片 | 玉米片 | 代餐 | 18.5 | 9 | 27 | 22 | 6 | 105 | 175 | clamp | K1 | 代餐 | 备注
S208 | 百草味代餐奶昔 | 代餐奶昔 | 代餐 | 25.5 | 9 | 27 | 22 | 6 | 105 | 175 | clamp | K1 | 代餐 | 备注
S209 | 良品铺子蛋白代餐饼 | 蛋白代餐饼 | 代餐 | 22.8 | 8 | 26 | 21 | 5 | 105 | 175 | clamp | K1 | 代餐 | 备注
S210 | 百草味原味开心果 | 原味开心果 | 坚果炒货 | 72.8 | 13 | 36 | 31 | 12 | 110 | 180 | suction | A1 | 坚果 | 备注
S211 | 百草味盐焗巴旦木 | 盐焗巴旦木 | 坚果炒货 | 41.5 | 15 | 37 | 32 | 13 | 110 | 180 | suction | A1 | 坚果 | 备注
S212 | 良品铺子原味碧根果 | 原味碧根果 | 坚果炒货 | 46.5 | 18 | 40 | 35 | 16 | 110 | 180 | suction | A1 | 坚果 | 备注
S213 | 百草味原味夏威夷果 | 原味夏威夷果 | 坚果炒货 | 53.8 | 70 | 95 | 95 | 20 | 20 | 38 | suction | A1 | 坚果 | 备注
S214 | 良品铺子杏仁巴旦木 | 杏仁巴旦木 | 坚果炒货 | 37.5 | 52 | 80 | 80 | 15 | 15 | 30 | suction | A1 | 坚果 | 备注
S215 | 恰恰薄皮核桃 | 薄皮核桃 | 坚果炒货 | 21.5 | 75 | 100 | 100 | 25 | 25 | 45 | suction | A1 | 坚果 | 备注
S216 | 里奈の零食鱿鱼仔 | 鱿鱼仔 | 海味 | 27.5 | 9 | 27 | 22 | 6 | 95 | 165 | clamp | E1 | 海味 | 备注
S217 | 有友泡花生 | 泡花生 | 炒货 | 13.8 | 9 | 27 | 22 | 6 | 80 | 150 | clamp | B1 | 炒货 | 备注
S218 | 蒙都风干牛肉干 | 风干牛肉干 | 肉干 | 43.5 | 11 | 29 | 24 | 8 | 100 | 170 | clamp | D1 | 肉干 | 备注
S219 | 茱蒂丝花生酱夹心饼干 | 花生酱夹心 | 饼干 | 17.8 | 7 | 25 | 20 | 5 | 75 | 145 | clamp | H1 | 饼干 | 备注
S220 | 米多奇烤香馍片 | 烤香馍片 | 饼干 | 14.5 | 7 | 25 | 20 | 5 | 75 | 145 | clamp | H1 | 饼干 | 备注
S221 | 友臣肉松饼 | 肉松饼 | 糕点 | 18.8 | 8 | 26 | 21 | 5 | 90 | 160 | clamp | I1 | 糕点 | 备注
S222 | 比比赞蔓越莓曲奇 | 蔓越莓曲奇 | 饼干 | 18.2 | 7 | 25 | 20 | 5 | 75 | 145 | clamp | H1 | 饼干 | 备注
S223 | 水益农盐焗鹌鹑蛋 | 盐焗鹌鹑蛋 | 卤味 | 16.5 | 7 | 25 | 20 | 5 | 85 | 155 | clamp | F1 | 卤味 | 备注
S224 | 良品铺子虎皮凤爪 | 虎皮凤爪 | 卤味 | 24.8 | 10 | 28 | 23 | 7 | 100 | 170 | clamp | D1 | 卤味 | 备注
S225 | 三只松鼠无骨鸡爪 | 无骨鸡爪 | 卤味 | 26.5 | 10 | 28 | 23 | 7 | 100 | 170 | clamp | D1 | 卤味 | 备注

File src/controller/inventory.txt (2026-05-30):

Fill in the file like ["乐事薯片", "奥利奥", "旺旺雪饼"]

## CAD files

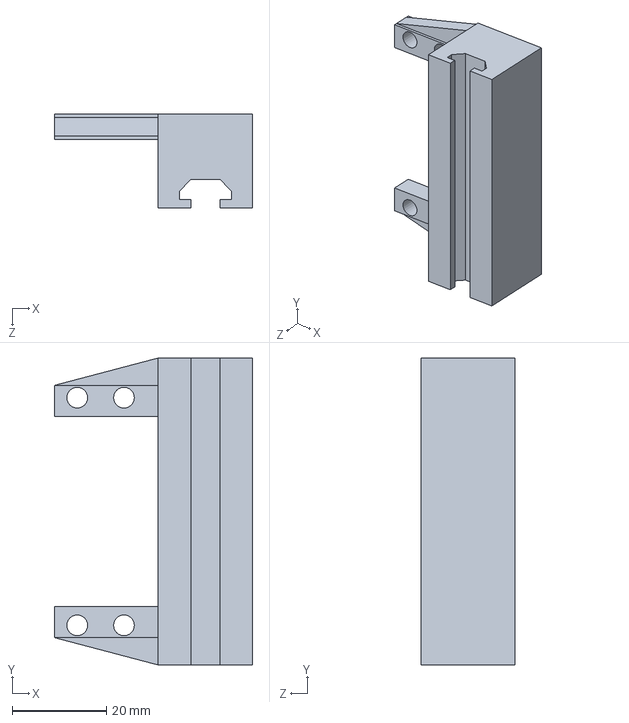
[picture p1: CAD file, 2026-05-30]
models/static.SLDPRT
42.0 x 65.0 x 20.0 mm

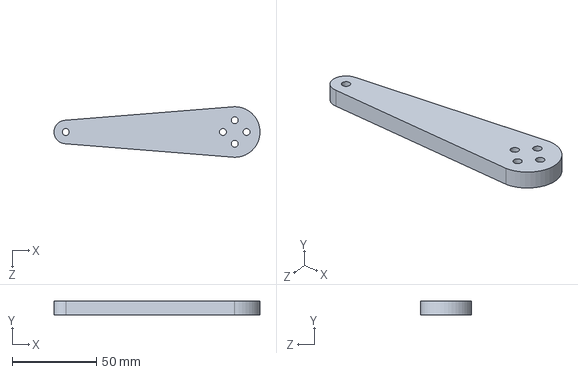
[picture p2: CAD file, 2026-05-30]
models/autoARM.SLDPRT
121.9 x 8.00 x 30.0 mm

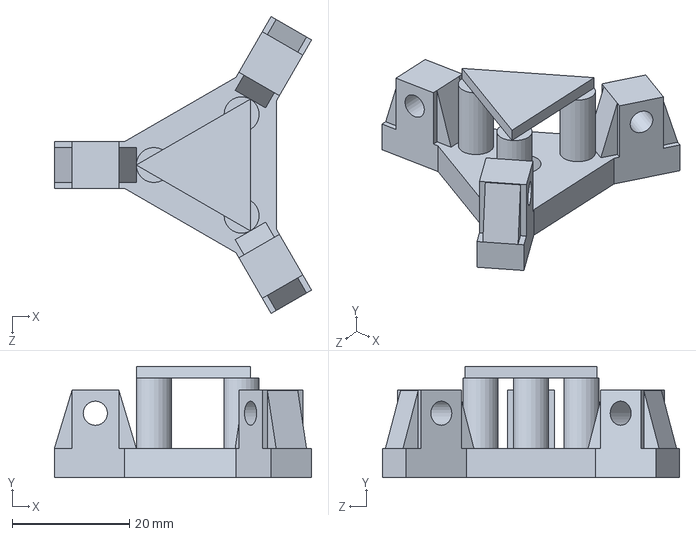
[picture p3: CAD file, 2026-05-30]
models/dynamic.SLDPRT
44.0 x 19.0 x 50.8 mm

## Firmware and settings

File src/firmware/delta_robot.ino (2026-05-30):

/**
 * ============================================================
 *  Delta Robot Controller — ESP32 + MG996R × 3  (FreeRTOS)
 * ============================================================
 *  底座半径 (f): 57.74 mm   主动臂 (rf): 100 mm
 *  从动臂 (re): 259 mm      动平台 (e):   20 mm
 *
 *  舵机: 臂0→D14(0°)  臂1→D12(120°)  臂2→D13(240°)
 *  坐标系: 原点底座中心，Z 向下为正
 *  驱动: LEDC   网络: WiFi STA + TCP :8266  协议: 纯文本 \n
 *
 *  任务布局:
 *    Core 1: MotionTask(5)  CommandTask(3)  WeighTask(3)  ButtonTask(2)
 *    Core 0: NetworkTask(3) SerialTask(2)
 * ============================================================
 */

#include <Arduino.h>
#include <math.h>
#include <WiFi.h>
#include <Preferences.h>
#include "HX711.h"

/* ── WiFi & TCP ── */
static const int TCP_PORT = 8266;
// SSID and password are stored in NVS via Preferences (namespace "wifi").
// On first boot (or after "setwifi <ssid> <pass>" serial command) they are
// written to flash and never appear in source code.
static char WIFI_SSID[64]     = "";
static char WIFI_PASSWORD[64] = "";

static WiFiServer tcpServer(TCP_PORT);
static WiFiClient tcpClient;

/* ── 机器人几何参数 (mm) ── */
static const float F  = 57.74f;
static const float E  = 20.0f;
static const float RF = 100.0f;
static const float RE = 259.0f;

/* ── 舵机 & LEDC ── */
static const int   SERVO_PIN[3]          = {14, 12, 13};
static const int   LEDC_FREQ             = 50;
static const int   LEDC_RESOLUTION       = 16;
static const int   LEDC_CHANNEL[3]       = {0, 1, 2};
static const int   PULSE_MIN_US          = 500;
static const int   PULSE_MAX_US          = 2500;
static const float MAX_SPEED_DEG_PER_SEC = 45.0f;
static const int   MOTION_INTERVAL_MS    = 10;
static const float SERVO_MIN_DEG         = 30.0f;
static const float SERVO_MAX_DEG         = 150.0f;
static const float SERVO_HOME_DEG        = 90.0f;

/* ── 气泵继电器 & 按钮 ── */
static const int   RELAY_PIN  = 26;
static const int   BUTTON_PIN = 27;

/* ── 称重台预设位置 ── */
static const float WEIGH_X = 195.0f;
static const float WEIGH_Y =   0.0f;
static const float WEIGH_Z = 150.0f;

/* ── HX711 ── */
static const int      HX711_DOUT        = 33;
static const int      HX711_SCK         = 32;
static const float    HX711_CALIBRATION = 2280.0f;  // 需按实物校准
static const uint32_t WEIGH_SETTLE_MS   = 1000;
static HX711 scale;

/* ── 工作空间安全限制 (mm) ── */
static const float WS_X_MIN = -100.0f, WS_X_MAX = 100.0f;
static const float WS_Y_MIN = -100.0f, WS_Y_MAX = 100.0f;
static const float WS_Z_MIN =   50.0f, WS_Z_MAX = 280.0f;

/* ── 几何常数 ── */
static const float ARM_ANGLE_DEG[3] = {0.0f, 120.0f, 240.0f};
static float cosA[3], sinA[3];

/* ── 共享状态（受 xStateMutex 保护）── */
static float currentAngle[3] = {90.0f, 90.0f, 90.0f};
static float currentX = -96.0f, currentY = 100.0f, currentZ = 264.0f;
static bool  pumpOn   = false;

/* ── RTOS 句柄 ── */
#define CMD_LEN 64
static QueueHandle_t     xCmdQueue;     // char[CMD_LEN]，深度 8，入站命令
static QueueHandle_t     xMotionQueue;  // float[3]，深度 1，目标舵机角度
static QueueHandle_t     xWeighQueue;   // uint8_t，深度 1，称重指令
static SemaphoreHandle_t xStateMutex;   // 保护 currentAngle/X/Y/Z/pumpOn
static SemaphoreHandle_t xClientMutex;  // 保护 tcpClient

#define WEIGH_CMD_MEASURE 0
#define WEIGH_CMD_TARE    1

/* ============================================================
   LEDC 工具函数
============================================================ */
static uint32_t pulseToCounts(uint32_t pulse_us) {
    uint32_t period_us = 1000000UL / LEDC_FREQ;
    uint32_t maxCnt    = (1UL << LEDC_RESOLUTION) - 1;
    return (uint32_t)((uint64_t)pulse_us * maxCnt / period_us);
}

static void servoWriteDeg(int ch, float deg) {
    if (deg < SERVO_MIN_DEG) deg = SERVO_MIN_DEG;
    if (deg > SERVO_MAX_DEG) deg = SERVO_MAX_DEG;
    float    frac     = deg / 180.0f;
    uint32_t pulse_us = (uint32_t)(PULSE_MIN_US + frac * (PULSE_MAX_US - PULSE_MIN_US));
    ledcWrite(LEDC_CHANNEL[ch], pulseToCounts(pulse_us));
}

static void servosInit() {
    for (int i = 0; i < 3; i++) {
        ledcSetup(LEDC_CHANNEL[i], LEDC_FREQ, LEDC_RESOLUTION);
        ledcAttachPin(SERVO_PIN[i], LEDC_CHANNEL[i]);
        servoWriteDeg(i, SERVO_HOME_DEG);
        currentAngle[i] = SERVO_HOME_DEG;
    }
}

/* ── 上电慢速归位（仅 setup 调用，调度器启动前）── */
static void servoMoveToBlocking(const float tgt[3], int steps = 30, int stepMs = 12) {
    float start[3];
    for (int i = 0; i < 3; i++) start[i] = currentAngle[i];
    for (int s = 1; s <= steps; s++) {
        float t = (float)s / steps;
        for (int i = 0; i < 3; i++) {
            float a = start[i] + t * (tgt[i] - start[i]);
            servoWriteDeg(i, a);
            currentAngle[i] = a;
        }
        delay(stepMs);
    }
}

/* ============================================================
   逆运动学
============================================================ */
static bool ikSingleArm(float xp, float yp, float zp, int armIdx, float &angleDeg) {
    float theta = ARM_ANGLE_DEG[armIdx] * (float)M_PI / 180.0f;
    float xRot  = xp * cosf(theta) + yp * sinf(theta);
    float delta = F - E;
    float x1    = xRot - delta;
    float z1    = zp;

    float A = -2.0f * RF * x1;
    float B = -2.0f * RF * z1;
    float C = RE * RE - RF * RF - x1 * x1 - z1 * z1;

    float R = sqrtf(A * A + B * B);
    if (R < 1e-6f) return false;
    float ratio = C / R;
    if (fabsf(ratio) > 1.0f) return false;

    float phi    = atan2f(B, A);
    float alpha  = acosf(ratio);
    float servo1 = 90.0f + (phi + alpha) * 180.0f / (float)M_PI;
    float servo2 = 90.0f + (phi - alpha) * 180.0f / (float)M_PI;
    bool  v1     = (servo1 >= SERVO_MIN_DEG && servo1 <= SERVO_MAX_DEG);
    bool  v2     = (servo2 >= SERVO_MIN_DEG && servo2 <= SERVO_MAX_DEG);

    if (!v1 && !v2) return false;
    float d1 = fabsf(servo1 - 90.0f), d2 = fabsf(servo2 - 90.0f);
    if (v1 && v2) angleDeg = (d1 <= d2) ? servo1 : servo2;
    else          angleDeg = v1 ? servo1 : servo2;
    return true;
}

static bool deltaIK(float x, float y, float z, float out[3]) {
    for (int i = 0; i < 3; i++)
        if (!ikSingleArm(x, y, z, i, out[i])) return false;
    return true;
}

/* ============================================================
   工作空间安全检查
============================================================ */
static bool checkWorkspace(float x, float y, float z) {
    if (x == WEIGH_X && y == WEIGH_Y && z == WEIGH_Z) return true;
    return (x >= WS_X_MIN && x <= WS_X_MAX &&
            y >= WS_Y_MIN && y <= WS_Y_MAX &&
            z >= WS_Z_MIN && z <= WS_Z_MAX);
}

/* ============================================================
   线程安全输出（Serial 本身线程安全；tcpClient 受 xClientMutex 保护）
============================================================ */
static void netPrint(const char* s) {
    Serial.print(s);
    xSemaphoreTake(xClientMutex, portMAX_DELAY);
    if (tcpClient && tcpClient.connected()) tcpClient.print(s);
    xSemaphoreGive(xClientMutex);
}
static void netPrintln(const char* s) {
    char buf[CMD_LEN + 2];
    snprintf(buf, sizeof(buf), "%s\n", s);
    netPrint(buf);
}
static void netPrintf(const char* fmt, ...) {
    char buf[128];
    va_list ap;
    va_start(ap, fmt);
    vsnprintf(buf, sizeof(buf), fmt, ap);
    va_end(ap);
    netPrint(buf);
}

/* ============================================================
   moveTo — 由 CommandTask 调用
============================================================ */
static void moveTo(float x, float y, float z) {
    netPrintf("[CMD] Target: (%.2f, %.2f, %.2f)\n", x, y, z);

    if (!checkWorkspace(x, y, z)) {
        netPrintf("[ERR] Out of safe workspace! X[%.0f,%.0f] Y[%.0f,%.0f] Z[%.0f,%.0f]\n",
                  WS_X_MIN, WS_X_MAX, WS_Y_MIN, WS_Y_MAX, WS_Z_MIN, WS_Z_MAX);
        return;
    }

    float angles[3];
    if (!deltaIK(x, y, z, angles)) {
        netPrintln("[ERR] IK no solution! Point unreachable.");
        return;
    }

    for (int i = 0; i < 3; i++) {
        if (angles[i] < SERVO_MIN_DEG || angles[i] > SERVO_MAX_DEG) {
            netPrintf("[ERR] Arm %d angle %.1f out of range [%.0f,%.0f]!\n",
                      i, angles[i], SERVO_MIN_DEG, SERVO_MAX_DEG);
            return;
        }
    }

    xQueueOverwrite(xMotionQueue, angles);

    xSemaphoreTake(xStateMutex, portMAX_DELAY);
    currentX = x; currentY = y; currentZ = z;
    xSemaphoreGive(xStateMutex);

    netPrintf("[OK] %.2f,%.2f,%.2f\n", x, y, z);
}

/* ============================================================
   handleCommand — 由 CommandTask 调用
============================================================ */
static void handleCommand(const char* raw) {
    char cmd[CMD_LEN];
    strncpy(cmd, raw, CMD_LEN - 1);
    cmd[CMD_LEN - 1] = '\0';

    // trim trailing whitespace
    int len = strlen(cmd);
    while (len > 0 && (cmd[len-1] == ' ' || cmd[len-1] == '\r')) cmd[--len] = '\0';
    if (len == 0) return;

    // lowercase copy for comparison
    char lo[CMD_LEN];
    for (int i = 0; i <= len; i++) lo[i] = tolower((unsigned char)cmd[i]);

    if (strcmp(lo, "home") == 0) {
        netPrintln("[CMD] Homing...");
        moveTo(-96.0f, 100.0f, 264.0f);
    } else if (strcmp(lo, "pos") == 0) {
        xSemaphoreTake(xStateMutex, portMAX_DELAY);
        float x = currentX, y = currentY, z = currentZ;
        float a0 = currentAngle[0], a1 = currentAngle[1], a2 = currentAngle[2];
        xSemaphoreGive(xStateMutex);
        netPrintf("[POS] %.2f,%.2f,%.2f\n", x, y, z);
        netPrintf("[ANG] %.1f,%.1f,%.1f\n", a0, a1, a2);
    } else if (strcmp(lo, "ping") == 0) {
        netPrintln("[PONG]");
    } else if (strcmp(lo, "pump_on") == 0) {
        xSemaphoreTake(xStateMutex, portMAX_DELAY);
        pumpOn = true;
        xSemaphoreGive(xStateMutex);
        digitalWrite(RELAY_PIN, HIGH);
        netPrintln("[PUMP] ON");
    } else if (strcmp(lo, "pump_off") == 0) {
        xSemaphoreTake(xStateMutex, portMAX_DELAY);
        pumpOn = false;
        xSemaphoreGive(xStateMutex);
        digitalWrite(RELAY_PIN, LOW);
        netPrintln("[PUMP] OFF");
    } else if (strcmp(lo, "pump") == 0) {
        xSemaphoreTake(xStateMutex, portMAX_DELAY);
        bool on = pumpOn;
        xSemaphoreGive(xStateMutex);
        netPrintf("[PUMP] %s\n", on ? "ON" : "OFF");
    } else if (strcmp(lo, "weigh") == 0) {
        netPrintln("[CMD] Moving to weigh position...");
        moveTo(WEIGH_X, WEIGH_Y, WEIGH_Z);
    } else if (strcmp(lo, "weight") == 0) {
        uint8_t c = WEIGH_CMD_MEASURE;
        xQueueOverwrite(xWeighQueue, &c);
    } else if (strcmp(lo, "tare") == 0) {
        uint8_t c = WEIGH_CMD_TARE;
        xQueueOverwrite(xWeighQueue, &c);
    } else if (strncmp(lo, "setwifi ", 8) == 0) {
        // Usage (serial only): setwifi <ssid> <password>
        // Saves credentials to NVS flash; reboot to apply.
        char tmp[CMD_LEN];
        strncpy(tmp, cmd + 8, CMD_LEN - 1);
        tmp[CMD_LEN - 1] = '\0';
        char *sp = strchr(tmp, ' ');
        if (!sp) { netPrintln("[ERR] Usage: setwifi <ssid> <password>"); return; }
        *sp = '\0';
        Preferences prefs;
        prefs.begin("wifi", false);
        prefs.putString("ssid", tmp);
        prefs.putString("pass", sp + 1);
        prefs.end();
        netPrintln("[OK] WiFi credentials saved. Reboot to apply.");
    } else {
        // try "x,y,z"
        char *p1 = strchr(cmd, ',');
        char *p2 = p1 ? strrchr(cmd, ',') : nullptr;
        if (p1 && p2 && p2 != p1) {
            *p1 = '\0'; *p2 = '\0';
            moveTo(atof(cmd), atof(p1 + 1), atof(p2 + 1));
        } else {
            netPrintf("[ERR] Unknown command: %s\n", cmd);
        }
    }
}

/* ============================================================
   taskMotion — Core 1, 优先级 5
   每 MOTION_INTERVAL_MS 推进一步插值，smoothstep ease-in-out
============================================================ */
static void taskMotion(void*) {
    float start[3], target[3];
    int   steps = 0, step = 0;
    bool  active = false;

    for (;;) {
        float newTgt[3];
        if (xQueueReceive(xMotionQueue, newTgt, 0) == pdTRUE) {
            xSemaphoreTake(xStateMutex, portMAX_DELAY);
            float maxDelta = 0.0f;
            for (int i = 0; i < 3; i++) {
                start[i] = currentAngle[i];
                float d = fabsf(newTgt[i] - currentAngle[i]);
                if (d > maxDelta) maxDelta = d;
            }
            xSemaphoreGive(xStateMutex);

            for (int i = 0; i < 3; i++) target[i] = newTgt[i];
            steps  = max(4, (int)(maxDelta / (MAX_SPEED_DEG_PER_SEC * MOTION_INTERVAL_MS * 0.001f)));
            step   = 0;
            active = true;
        }

        if (active) {
            step++;
            float t = (float)step / (float)steps;
            if (t > 1.0f) t = 1.0f;
            float s = t * t * (3.0f - 2.0f * t);  // smoothstep

            xSemaphoreTake(xStateMutex, portMAX_DELAY);
            for (int i = 0; i < 3; i++) {
                float a = start[i] + s * (target[i] - start[i]);
                servoWriteDeg(i, a);
                currentAngle[i] = a;
            }
            xSemaphoreGive(xStateMutex);

            if (t >= 1.0f) active = false;
        }

        vTaskDelay(pdMS_TO_TICKS(MOTION_INTERVAL_MS));
    }
}

/* ============================================================
   taskWeigh — Core 1, 优先级 3
   收到 MEASURE: 采 before → 等待稳定 → 采 after → 回复差值
   收到 TARE:    执行归零
============================================================ */
static void taskWeigh(void*) {
    for (;;) {
        uint8_t cmd;
        xQueueReceive(xWeighQueue, &cmd, portMAX_DELAY);

        if (cmd == WEIGH_CMD_TARE) {
            scale.tare();
            netPrintln("[TARE] Done.");
            continue;
        }

        if (!scale.is_ready()) { netPrintln("[ERR] HX711 not ready."); continue; }
        float before = scale.get_units(10);
        vTaskDelay(pdMS_TO_TICKS(WEIGH_SETTLE_MS));
        if (!scale.is_ready()) { netPrintln("[ERR] HX711 not ready."); continue; }
        float after = scale.get_units(10);
        netPrintf("[WEIGHT] %.2f g\n", after - before);
    }
}

/* ============================================================
   taskButton — Core 1, 优先级 2
   软件防抖 50ms，按下沿 toggle 气泵
============================================================ */
static void taskButton(void*) {
    bool     lastRaw    = HIGH;
    bool     stable     = HIGH;
    uint32_t debounceMs = 0;

    for (;;) {
        bool raw = digitalRead(BUTTON_PIN);
        if (raw != lastRaw) { debounceMs = millis(); lastRaw = raw; }
        if (millis() - debounceMs > 50 && raw != stable) {
            stable = raw;
            if (stable == LOW) {
                xSemaphoreTake(xStateMutex, portMAX_DELAY);
                pumpOn = !pumpOn;
                bool on = pumpOn;
                xSemaphoreGive(xStateMutex);
                digitalWrite(RELAY_PIN, on ? HIGH : LOW);
                netPrintln(on ? "[PUMP] ON (button)" : "[PUMP] OFF (button)");
            }
        }
        vTaskDelay(pdMS_TO_TICKS(10));
    }
}

/* ============================================================
   taskCommand — Core 1, 优先级 3
   从 xCmdQueue 取命令并分发
============================================================ */
static void taskCommand(void*) {
    char buf[CMD_LEN];
    for (;;) {
        if (xQueueReceive(xCmdQueue, buf, portMAX_DELAY) == pdTRUE)
            handleCommand(buf);
    }
}

/* ============================================================
   taskSerial — Core 0, 优先级 2
   读串口行，推入 xCmdQueue
============================================================ */
static void taskSerial(void*) {
    char    line[CMD_LEN];
    uint8_t pos = 0;

    for (;;) {
        while (Serial.available()) {
            char c = (char)Serial.read();
            if (c == '\n') {
                line[pos] = '\0';
                if (pos > 0) xQueueSend(xCmdQueue, line, 0);
                pos = 0;
            } else if (c != '\r' && pos < CMD_LEN - 1) {
                line[pos++] = c;
            }
        }
        vTaskDelay(pdMS_TO_TICKS(5));
    }
}

/* ============================================================
   taskNetwork — Core 0, 优先级 3
   WiFi 管理 + TCP accept/receive，推入 xCmdQueue
============================================================ */
static void taskNetwork(void*) {
    Serial.printf("[WiFi] Connecting to %s", WIFI_SSID);
    WiFi.mode(WIFI_STA);
    WiFi.setAutoReconnect(true);
    WiFi.persistent(false);
    WiFi.begin(WIFI_SSID, WIFI_PASSWORD);
    for (int t = 0; t < 40 && WiFi.status() != WL_CONNECTED; t++) {
        vTaskDelay(pdMS_TO_TICKS(500));
        Serial.print('.');
    }
    if (WiFi.status() == WL_CONNECTED) {
        Serial.printf("\n[WiFi] IP: %s  TCP:%d\n",
                      WiFi.localIP().toString().c_str(), TCP_PORT);
        tcpServer.begin();
    } else {
        Serial.println("\n[WiFi] FAILED — serial-only mode.");
    }

    char    tcpBuf[CMD_LEN];
    uint8_t tcpPos    = 0;
    uint32_t lastPing = millis();

    for (;;) {
        /* 掉线重连 */
        if (WiFi.status() != WL_CONNECTED) {
            static uint32_t lastReconn = 0;
            if (millis() - lastReconn > 5000) {
                lastReconn = millis();
                Serial.println("[WiFi] Reconnecting...");
                WiFi.reconnect();
            }
            vTaskDelay(pdMS_TO_TICKS(200));
            continue;
        }

        /* 接受新连接 */
        xSemaphoreTake(xClientMutex, portMAX_DELAY);
        bool connected = tcpClient && tcpClient.connected();
        xSemaphoreGive(xClientMutex);

        if (!connected) {
            WiFiClient nc = tcpServer.available();
            if (nc) {
                xSemaphoreTake(xClientMutex, portMAX_DELAY);
                if (tcpClient) tcpClient.stop();
                tcpClient = nc;
                tcpClient.setNoDelay(true);
                xSemaphoreGive(xClientMutex);
                tcpPos  = 0;
                lastPing = millis();
                Serial.printf("[TCP] Client: %s\n", nc.remoteIP().toString().c_str());
                netPrintln("[HELLO] Delta Robot ready.");
            }
        }

        /* 接收数据 */
        xSemaphoreTake(xClientMutex, portMAX_DELAY);
        bool avail = tcpClient && tcpClient.connected() && tcpClient.available();
        xSemaphoreGive(xClientMutex);

        if (avail) {
            xSemaphoreTake(xClientMutex, portMAX_DELAY);
            while (tcpClient.available()) {
                char c = (char)tcpClient.read();
                if (c == '\n') {
                    tcpBuf[tcpPos] = '\0';
                    if (tcpPos > 0) {
                        xQueueSend(xCmdQueue, tcpBuf, 0);
                        lastPing = millis();
                    }
                    tcpPos = 0;
                } else if (c != '\r' && tcpPos < CMD_LEN - 1) {
                    tcpBuf[tcpPos++] = c;
                }
            }
            xSemaphoreGive(xClientMutex);
        }

        /* 超时断开 */
        if (millis() - lastPing > 30000) {
            xSemaphoreTake(xClientMutex, portMAX_DELAY);
            if (tcpClient) { Serial.println("[TCP] Timeout."); tcpClient.stop(); }
            xSemaphoreGive(xClientMutex);
            lastPing = millis();
        }

        vTaskDelay(pdMS_TO_TICKS(5));
    }
}

/* ============================================================
   Arduino 入口
============================================================ */
void setup() {
    Serial.begin(115200);
    delay(500);

    // Load WiFi credentials from NVS (written once via "setwifi <ssid> <pass>" serial command)
    {
        Preferences prefs;
        prefs.begin("wifi", true);
        String s = prefs.getString("ssid", "");
        String p = prefs.getString("pass", "");
        prefs.end();
        if (s.length() == 0) {
            Serial.println("[WARN] No WiFi credentials in NVS. Send: setwifi <ssid> <password>");
        }
        s.toCharArray(WIFI_SSID,     sizeof(WIFI_SSID));
        p.toCharArray(WIFI_PASSWORD, sizeof(WIFI_PASSWORD));
    }

    for (int i = 0; i < 3; i++) {
        float rad = ARM_ANGLE_DEG[i] * (float)M_PI / 180.0f;
        cosA[i] = cosf(rad);
        sinA[i] = sinf(rad);
    }

    Serial.println("\n======================================");
    Serial.println("  Delta Robot — ESP32 FreeRTOS v3.0");
    Serial.println("======================================");

    servosInit();
    Serial.println("[INIT] Servos homed (90 deg)");
    delay(800);

    pinMode(RELAY_PIN, OUTPUT);
    digitalWrite(RELAY_PIN, LOW);
    Serial.println("[INIT] Pump driver initialized (pump OFF)");

    pinMode(BUTTON_PIN, INPUT_PULLUP);
    Serial.println("[INIT] Button initialized");

    scale.begin(HX711_DOUT, HX711_SCK);
    scale.set_scale(HX711_CALIBRATION);
    scale.tare();
    Serial.println("[INIT] HX711 initialized, tared.");
    delay(800);

    xCmdQueue    = xQueueCreate(8, CMD_LEN);
    xMotionQueue = xQueueCreate(1, sizeof(float) * 3);
    xWeighQueue  = xQueueCreate(1, sizeof(uint8_t));
    xStateMutex  = xSemaphoreCreateMutex();
    xClientMutex = xSemaphoreCreateMutex();

    xTaskCreatePinnedToCore(taskMotion,  "Motion",  2048, nullptr, 5, nullptr, 1);
    xTaskCreatePinnedToCore(taskCommand, "Command", 4096, nullptr, 3, nullptr, 1);
    xTaskCreatePinnedToCore(taskWeigh,   "Weigh",   2048, nullptr, 3, nullptr, 1);
    xTaskCreatePinnedToCore(taskButton,  "Button",  1024, nullptr, 2, nullptr, 1);
    xTaskCreatePinnedToCore(taskSerial,  "Serial",  2048, nullptr, 2, nullptr, 0);
    xTaskCreatePinnedToCore(taskNetwork, "Network", 4096, nullptr, 3, nullptr, 0);

    Serial.println("[READY] All tasks started.");
}

void loop() {
    vTaskDelay(portMAX_DELAY);
}

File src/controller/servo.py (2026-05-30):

import time

import numpy as np

from .camera import CameraStream, undistort
from .config import (
    CAMERA_OFFSET_U, CAMERA_OFFSET_V,
    CENTER_Z_MM,
    DESCEND_SETTLE_S, DESCEND_STEP_MM, DESCEND_Z_MAX,
    SERVO_KD, SERVO_KI, SERVO_KP, SERVO_MAX_ITER, SERVO_MAX_STEP_MM,
    SERVO_SETTLE_S, SERVO_TOL_PX, SERVO_Z_MM,
    WEIGH_X_MM, WEIGH_Y_MM, WEIGH_Z_MM,
    WS,
)
from .pid import PIDController
from .robot import Robot
from .vision import draw_aruco


def servo_to_target(
    target_px:   tuple[int, int],
    cap:         CameraStream,
    map1, map2,
    detect_aruco,
    robot:       "Robot | None",
    pid:         PIDController,
) -> bool:
    """
    PID visual servo main loop.

    Uses the ArUco#ARUCO_TARGET_ID pixel centre as the platform's current position feedback,
    iteratively controls the robot X/Y to align the ArUco centre with the target pixel centre.
    Z axis is fixed at SERVO_Z_MM.

    Returns True = converged, False = exceeded max iterations or ArUco lost.
    """
    pid.reset()
    tx, ty = target_px
    tx += CAMERA_OFFSET_U
    ty += CAMERA_OFFSET_V

    if robot is not None:
        pos = robot.get_pos()
        if pos is None:
            print("[Servo] Cannot get current position, aborting")
            return False
        cur_x, cur_y, _ = pos
        ok = robot.move_to(cur_x, cur_y, SERVO_Z_MM)
        if not ok:
            print("[Servo] Height preset failed, aborting")
            return False
        time.sleep(SERVO_SETTLE_S)
        cur_x_mm, cur_y_mm = cur_x, cur_y
    else:
        cur_x_mm, cur_y_mm = 0.0, 0.0

    print(f"[Servo] Starting servo  target_px=({tx},{ty})  Z={SERVO_Z_MM}mm")
    print(f"        gains Kp={SERVO_KP} Ki={SERVO_KI} Kd={SERVO_KD}  "
          f"tol={SERVO_TOL_PX}px  max_step={SERVO_MAX_STEP_MM}mm")

    for iteration in range(1, SERVO_MAX_ITER + 1):
        time.sleep(SERVO_SETTLE_S)
        ret, frame = cap.read()
        if not ret:
            print("[Servo] Frame capture failed, skipping")
            continue
        frame = undistort(frame, map1, map2)

        _, aruco_center = draw_aruco(frame, detect_aruco)
        if aruco_center is None:
            print(f"[Servo] iter {iteration}: ArUco lost, skipping frame")
            if robot:
                robot.ping()
            continue

        ax, ay = aruco_center
        err_u = tx - ax
        err_v = ty - ay
        err_norm = (err_u ** 2 + err_v ** 2) ** 0.5

        print(f"[Servo] iter={iteration:02d}  "
              f"ArUco=({ax},{ay})  target=({tx},{ty})  "
              f"err=({err_u:+.0f},{err_v:+.0f})px  |err|={err_norm:.1f}px")

        if err_norm < SERVO_TOL_PX:
            print(f"[Servo] ✓ Converged! error {err_norm:.1f}px < {SERVO_TOL_PX}px  "
                  f"iterations={iteration}")
            return True

        err_vec = np.array([err_u, err_v], dtype=float)
        delta   = pid.step(err_vec)

        # Camera mounted rotated: image +u → robot -Y, image +v → robot -X
        dx_mm = -delta[1]
        dy_mm = -delta[0]

        new_x = float(np.clip(cur_x_mm + dx_mm, WS["x_min"], WS["x_max"]))
        new_y = float(np.clip(cur_y_mm + dy_mm, WS["y_min"], WS["y_max"]))

        print(f"         PID Δ=({dx_mm:+.2f},{dy_mm:+.2f})mm  "
              f"→ sending ({new_x:+.2f},{new_y:+.2f},{SERVO_Z_MM:.1f})")

        if robot is not None:
            ok = robot.move_to(new_x, new_y, SERVO_Z_MM)
            if not ok:
                print("[Servo] Command rejected (out of range or IK infeasible), aborting")
                return False
            time.sleep(SERVO_SETTLE_S)
        else:
            print(f"[Servo] (no-robot) simulated move ({new_x:+.2f},{new_y:+.2f},{SERVO_Z_MM:.1f})")
            time.sleep(0.1)

        cur_x_mm, cur_y_mm = new_x, new_y

    print(f"[Servo] ✗ Reached max iterations {SERVO_MAX_ITER}, did not converge")
    return False


def descend_and_pick(robot: "Robot | None") -> "float | None":
    """
    The platform is already directly above the target (Z=SERVO_Z_MM); execute the full pick sequence:
      1. Slowly descend until the pump button triggers
      2. Lift to safe height, move to the weighing station
      3. Trigger weighing (firmware samples before≈0g), turn off pump to release the item
      4. Firmware waits 1s then samples after, pushes [WEIGHT] response

    Returns: item weight (g), None on failure, 0.0 in no-robot mode.
    """
    if robot is None:
        print("[Pick] no-robot mode, skipping pick sequence")
        return 0.0

    pos = robot.get_pos()
    if pos is None:
        print("[Pick] Cannot get current position, aborting")
        return None
    cur_x, cur_y, cur_z = pos
    print(f"\n[Pick] Starting descent  current_pos=({cur_x:.1f},{cur_y:.1f},{cur_z:.1f})")

    robot.check_and_clear_pump_trigger()

    pump_triggered = False
    while cur_z < DESCEND_Z_MAX:
        cur_z = min(cur_z + DESCEND_STEP_MM, DESCEND_Z_MAX)
        ok = robot.move_to(cur_x, cur_y, cur_z)
        if not ok:
            print(f"[Pick] Descent command rejected (Z={cur_z:.1f}mm), stopping")
            return None
        time.sleep(DESCEND_SETTLE_S)

        if robot.check_and_clear_pump_trigger():
            print(f"[Pick] Pump triggered! Stopping descent  Z={cur_z:.1f}mm")
            pump_triggered = True
            time.sleep(1)
            break

    if not pump_triggered:
        print("[Pick] No pump trigger detected, reached max depth, continuing")
        robot.pump_on()
        time.sleep(1)

    # Nudge upward to compensate for over-descent
    robot.move_to(cur_x, cur_y, cur_z - 15)
    time.sleep(2)

    print(f"[Pick] Lifting to safe height Z={CENTER_Z_MM}mm")
    ok = robot.move_to(cur_x, cur_y, CENTER_Z_MM)
    if ok:
        time.sleep(1.2)

    print(f"[Pick] Moving to weighing station ({WEIGH_X_MM}, {WEIGH_Y_MM}, {WEIGH_Z_MM})")
    ok = robot.move_to(WEIGH_X_MM, WEIGH_Y_MM, WEIGH_Z_MM)
    if ok:
        time.sleep(1.5)

    # Trigger weighing: firmware immediately samples 'before' (item still held by pump, scale≈0g),
    # then waits 1s; we turn off the pump to release the item during that window,
    # firmware then samples 'after' = item weight.
    # Sleep 200ms after start_weigh to ensure the firmware has sampled 'before'
    # before pump_off arrives, avoiding a race on high-latency TCP links.
    print("[Pick] Triggering weigh, turning off pump to release item...")
    robot.start_weigh()
    time.sleep(0.2)
    robot.pump_off()

    weight = robot.read_weight()
    if weight is not None:
        print(f"[Pick] Item weight: {weight:.2f} g")
    else:
        print("[Pick] Weighing failed (timeout or sensor error)")

    time.sleep(1.0)
    print("[Pick] Sequence complete, parked at weighing station")
    return weight
